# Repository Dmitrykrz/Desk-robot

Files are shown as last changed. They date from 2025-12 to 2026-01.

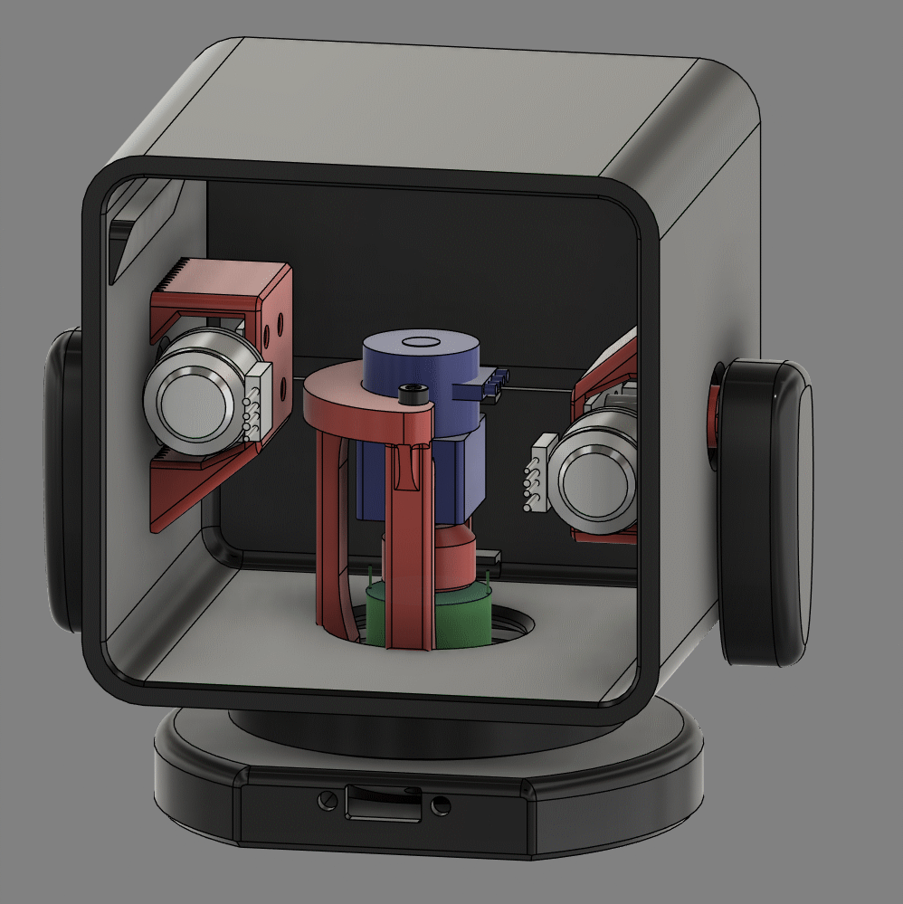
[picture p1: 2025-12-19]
Hardware/internal.png

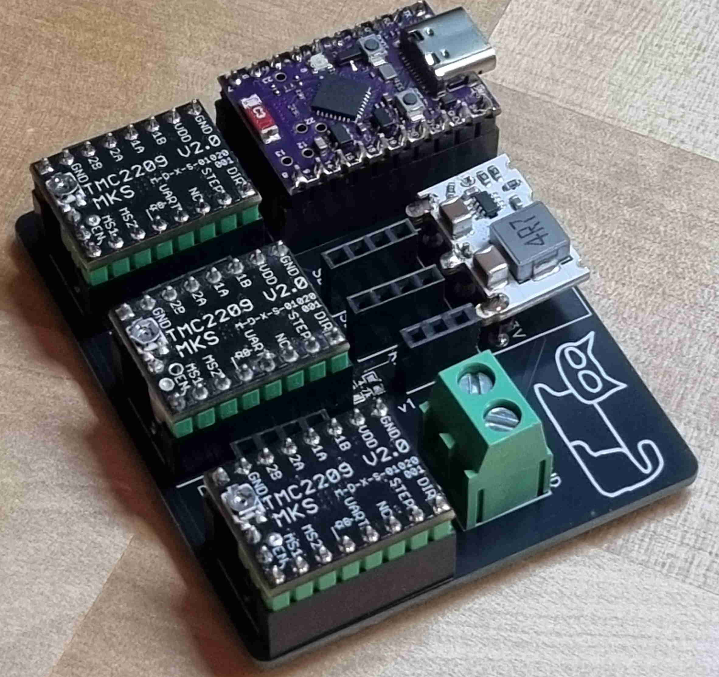
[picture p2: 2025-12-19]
Photos/Desk robot (2).jpg

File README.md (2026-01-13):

# Desk Robot Companion

https://github.com/user-attachments/assets/8fcd8911-27cb-44df-8bd5-095555234ec2

## What is it for?

As with all my projects, I build first and ask questions later. Now that it exists, the answer is clear: this little companion sits on my desk, waves at me when I return from coffee breaks, performs choreographed dances when bored, and generally serves as the world's most overengineered desk buddy.

It detects when I'm present, judges me silently with its LED face, and occasionally spins around dramatically for no reason.

Productivity tool? Emotional support robot? Procrastination enabler? Yes.

Due to the polarizing film with diffuser, the screen is notoriously difficult to capture on camera. It looks far better in person than in any photo here.
The low-ISO image below better represents the real appearance. I love this retro yellow vibe. Each pixel transforms from a point into a vertical rectangle, an artifact of two polarizing films cut at an angle. It gives the face a warmth and texture that photos simply cannot convey.



## Project Structure

- **PCB** — Files and photos for the custom circuit board
- **Hardware** — Fusion 360 design files for the robot body
- **Software** — Arduino code for ESP32-C6

## How It Works

### The Spin

The robot rotates on a large bearing with a 3mm steel shaft running through its center, connecting base to body. A hollow slip ring wraps around this shaft, passing USB power from the stationary base to the spinning upper body—unlimited rotation, no tangled wires, maximum drama.

The base motor drives through a 1:34 gearbox for smooth, theatrical rotations.
internal cut

### The Wave

Both arms use tiny stepper motors with integrated worm gears, giving them that slow, deliberate wave that says *"I acknowledge your existence, human."*

### The Brain

Three TMC2209 stepper drivers live on a custom PCB, commanded by an ESP32-C6. The firmware runs a timeline-based animation system—choreographed sequences of motor movements and facial expressions, all scheduled down to the millisecond.

Desk robot (2)

Desk robot (7)

### The Awareness

A radar module hides behind the face, detecting humans up to 8 meters away. When you approach, it wakes. When you leave, it sulks. The radar's wide spread means no sneaking past unnoticed.

### The Face

An Adafruit Charlieplexed LED matrix—warm yellow, delightfully retro. This display started everything. I saw its glow, imagined a tiny robot companion with emotions rendered in chunky pixels, and the rest became inevitable.

### The Dashboard
The robot is controlled via dashboard built on Node-red. It can be used for manual motor control and for creating face animations



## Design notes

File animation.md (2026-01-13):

# Desk Robot Animation System

## Overview

Timeline-based animation system for ESP32 desk robot with 3 stepper motors and LED matrix face. Commands are scheduled by millisecond timestamps and execute non-blocking in the main loop.

## Hardware

- **base**: Rotating body (stepper motor)
- **left**: Left arm (stepper motor)
- **right**: Right arm (stepper motor)
- **screen**: 8x16 LED matrix displaying emotions (images loaded from Preferences storage)

## Animation JSON Format

Send via MQTT to topic `desk_robot`:
```json
{
  "animation": [
    {"ms": 0, "motor": "base", "pos": 200, "spd": 400, "acc": 800},
    {"ms": 0, "motor": "left", "pos": 100, "spd": 600, "acc": 1200},
    {"ms": 500, "motor": "left", "pos": -100},
    {"ms": 1000, "screen_name": "happy"}    
  ]
}
```

## Command Fields

### Motor commands (base, left, right)

| Field | Required | Description |
|---|---|---|
| `ms` | Yes | Time in milliseconds from animation start |
| `motor` | Yes | Motor: `"base"`, `"left"`, or `"right"` |
| `pos` | Yes | Target position in steps |
| `spd` | No | Speed (steps/sec). If omitted, retains previous value |
| `acc` | No | Acceleration (steps/sec²). If omitted, retains previous value |

### Screen commands

| Field | Required | Description |
|---|---|---|
| `ms` | Yes | Time in milliseconds from animation start |
| `screen` | Yes (or use `screen_name` or `screen_data`) | Image name saved in Preferences (legacy) |
| `screen_name` | Yes (or use `screen` or `screen_data`) | Image name saved in Preferences |
| `screen_data` | Yes (or use `screen` or `screen_name`) | Raw 128-character image data string (8×16, `0` or `1`) |

**Note**: Use either `screen`/`screen_name` (to load saved image) OR `screen_data` (to display raw data without saving).

## Behavior

- Commands must be sorted by `ms` value (ascending)
- Commands with same `ms` value execute together
- Motors operate independently and simultaneously
- Speed/acceleration persist per motor until explicitly changed
- Animation completes when all commands dispatched and all motors stopped
- Maximum 50 commands per animation

## MQTT Responses

Published to `desk_robot_send`:

- `{"animation_started": true, "commands": N}` — animation begun
- `{"animation_complete": true}` — animation finished
- `{"animation_stopped": true}` — animation halted by command

## Animation Control
```json
{"animation_stop": 1}
```
Immediately halts animation and all motors.

## Direct Motor Control

### Base motor

| Command | Description |
|---|---|
| `{"base_move": 200}` | Move base to position 200 |
| `{"base_speed": 400}` | Set speed (also sets acceleration to speed × 2) |
| `{"base_acc": 800}` | Set acceleration independently |
| `{"base_zero": 1}` | Set current position as zero (no movement) |

### Left arm motor

| Command | Description |
|---|---|
| `{"left_move": 200}` | Move left arm to position (-1000 to 1000) |
| `{"left_speed": 400}` | Set speed (also sets acceleration to speed × 2) |
| `{"left_acc": 800}` | Set acceleration independently |
| `{"left_zero": 1}` | Set current position as zero (no movement) |

### Right arm motor

| Command | Description |
|---|---|
| `{"right_move": 200}` | Move right arm to position (-1000 to 1000) |
| `{"right_speed": 400}` | Set speed (also sets acceleration to speed × 2) |
| `{"right_acc": 800}` | Set acceleration independently |
| `{"right_zero": 1}` | Set current position as zero (no movement) |

### All motors

| Command | Description |
|---|---|
| `{"all_zero": 1}` | Set all motors' current position as zero |
| `{"all_home": 1}` | Move all motors to position 0 |

## Screen/Image Commands

### Display image directly

Send 128-character string (8 rows × 16 columns, `0` or `1`): must be 128 long

example of smile face:
{"image":"00100000000001000101000000001010010100000000101001010000000010100010000000000100000000000000000000001000000100000000011111100000"}
example sad face:
{"image":"00100000000001000101000000001010010100000000101000100000000001000000000000000000000001111110000000001100001100000001000000001000"}

### Save current image to storage
```json
{"image_save": "myimage"}
```
Image name must be 1-15 characters. Maximum 10 saved images.

### Load and display saved image
```json
{"image_show": "myimage"}
```

### List all saved images
```json
{"image_show_all": true}
```
Returns: `{"saved_images": ["image1", "image2", ...]}`

### Delete saved image
```json
{"image_delete": "myimage"}
```

## Radar Control

| Command | Description |
|---|---|
| `{"radarenable": 1}` | Enable radar human detection |
| `{"radarenable": 0}` | Disable radar human detection |

When enabled, publishes `{"human": 1}` or `{"human": 0}` on detection changes.

## System Commands

| Command | Description |
|---|---|
| `{"command": "reset"}` | Restart the ESP32 |

## Example Animations

### Animation with raw image data (no saving required)
```json
{
  "animation": [
    {"ms": 0, "screen_data": "00100000000001000101000000001010010100000000101001010000000010100010000000000100000000000000000000001000000100000000011111100000"},
    {"ms": 500, "screen_data": "00100000000001000101000000001010010100000000101000100000000001000000000000000000000001111110000000001100001100000001000000001000"},
    {"ms": 1000, "screen_name": "smile1"}
  ]
}
```

### Simple wave
```json
{
  "animation": [
    {"ms": 0, "motor": "left", "pos": 200, "spd": 800, "acc": 1600},
    {"ms": 300, "motor": "left", "pos": -200},
    {"ms": 600, "motor": "left", "pos": 200},
    {"ms": 900, "motor": "left", "pos": -200},
    {"ms": 1200, "motor": "left", "pos": 0}
  ]
}
```

### Dance (base rotation with arm waves)
```json
{
  "animation": [
    {"ms": 0, "screen": "happy"},
    {"ms": 0, "motor": "base", "pos": 300, "spd": 100, "acc": 200},
    {"ms": 0, "motor": "left", "pos": 200, "spd": 800, "acc": 1600},
    {"ms": 0, "motor": "right", "pos": -200, "spd": 800, "acc": 1600},
    {"ms": 400, "motor": "left", "pos": -200},
    {"ms": 400, "motor": "right", "pos": 200},
    {"ms": 800, "motor": "left", "pos": 200},
    {"ms": 800, "motor": "right", "pos": -200},
    {"ms": 1200, "motor": "left", "pos": -200},
    {"ms": 1200, "motor": "right", "pos": 200},
    {"ms": 1600, "motor": "left", "pos": 0},
    {"ms": 1600, "motor": "right", "pos": 0},
    {"ms": 2000, "motor": "base", "pos": 0},
    {"ms": 2500, "screen": "smile"}
  ]
}
```

### Excited greeting (fast arm movement while nodding)
```json
{
  "animation": [
    {"ms": 0, "screen": "excited"},
    {"ms": 0, "motor": "left", "pos": 300, "spd": 1000, "acc": 2000},
    {"ms": 0, "motor": "right", "pos": 300, "spd": 1000, "acc": 2000},
    {"ms": 0, "motor": "base", "pos": 50, "spd": 200, "acc": 800},
    {"ms": 200, "motor": "left", "pos": 100},
    {"ms": 200, "motor": "right", "pos": 100},
    {"ms": 200, "motor": "base", "pos": -50},
    {"ms": 400, "motor": "left", "pos": 300},
    {"ms": 400, "motor": "right", "pos": 300},
    {"ms": 400, "motor": "base", "pos": 50},
    {"ms": 600, "motor": "left", "pos": 100},
    {"ms": 600, "motor": "right", "pos": 100},
    {"ms": 600, "motor": "base", "pos": -50},
    {"ms": 800, "motor": "left", "pos": 0},
    {"ms": 800, "motor": "right", "pos": 0},
    {"ms": 800, "motor": "base", "pos": 0},
    {"ms": 1000, "screen": "smile"}
  ]
}
```

## Jog Commands (Relative Movement)

Jog commands move motors relative to their current position, unlike `*_move` commands which use absolute positioning.

| Command | Description |
|---|---|
| `{"base_jog": 100}` | Move base 100 steps from current position |
| `{"base_jog": -100}` | Move base -100 steps from current position |
| `{"left_jog": 50}` | Move left arm 50 steps from current position |
| `{"left_jog": -50}` | Move left arm -50 steps from current position |
| `{"right_jog": 50}` | Move right arm 50 steps from current position |
| `{"right_jog": -50}` | Move right arm -50 steps from current position |

Jog commands are useful for manual positioning and fine-tuning without tracking absolute positions.

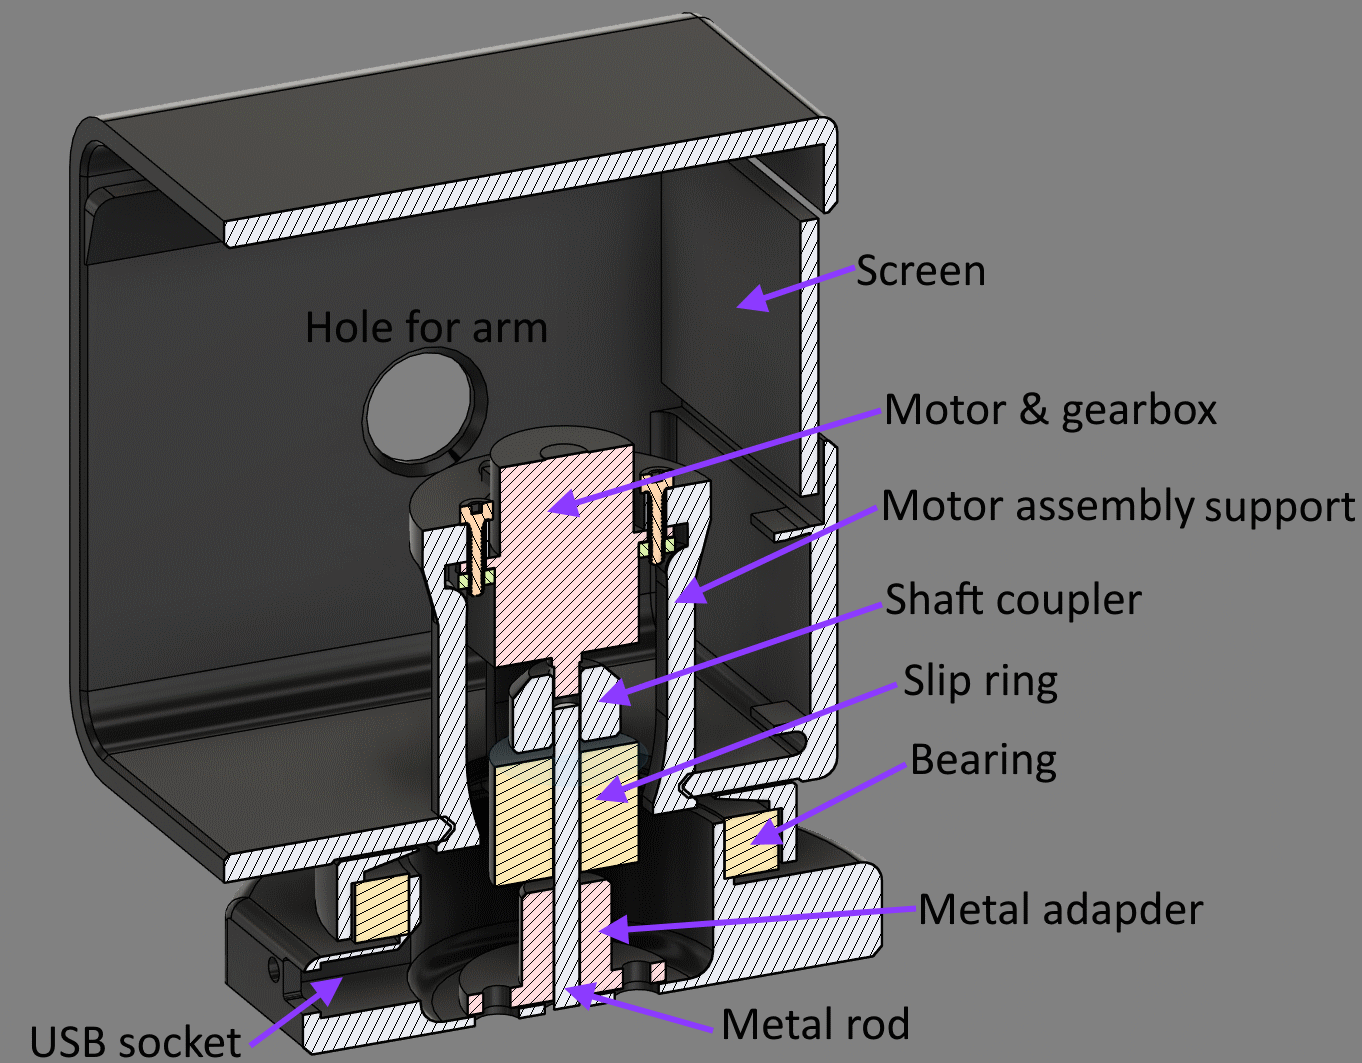
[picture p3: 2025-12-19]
Hardware/internal cut.png

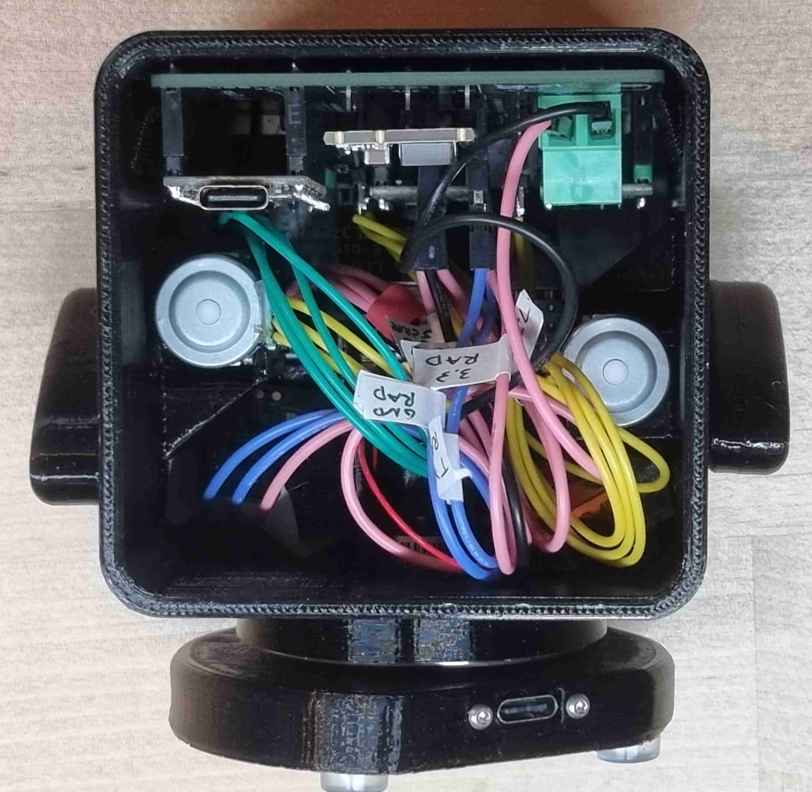
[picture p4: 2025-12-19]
Photos/Desk robot (7).jpg

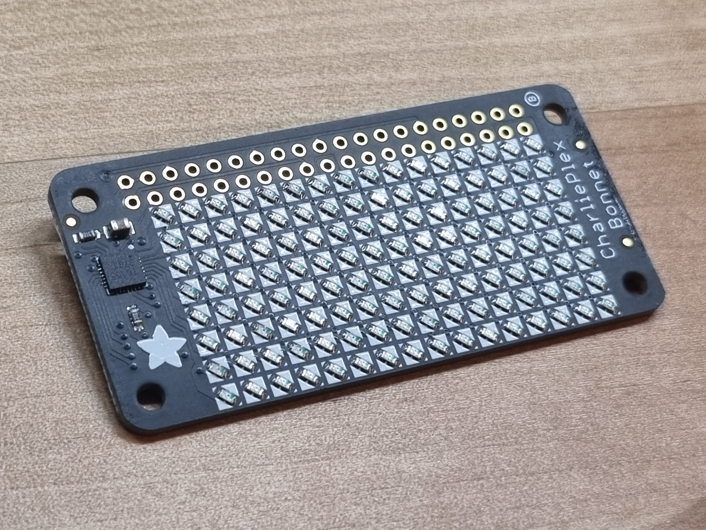
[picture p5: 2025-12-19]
Photos/Desk robot (5).jpg

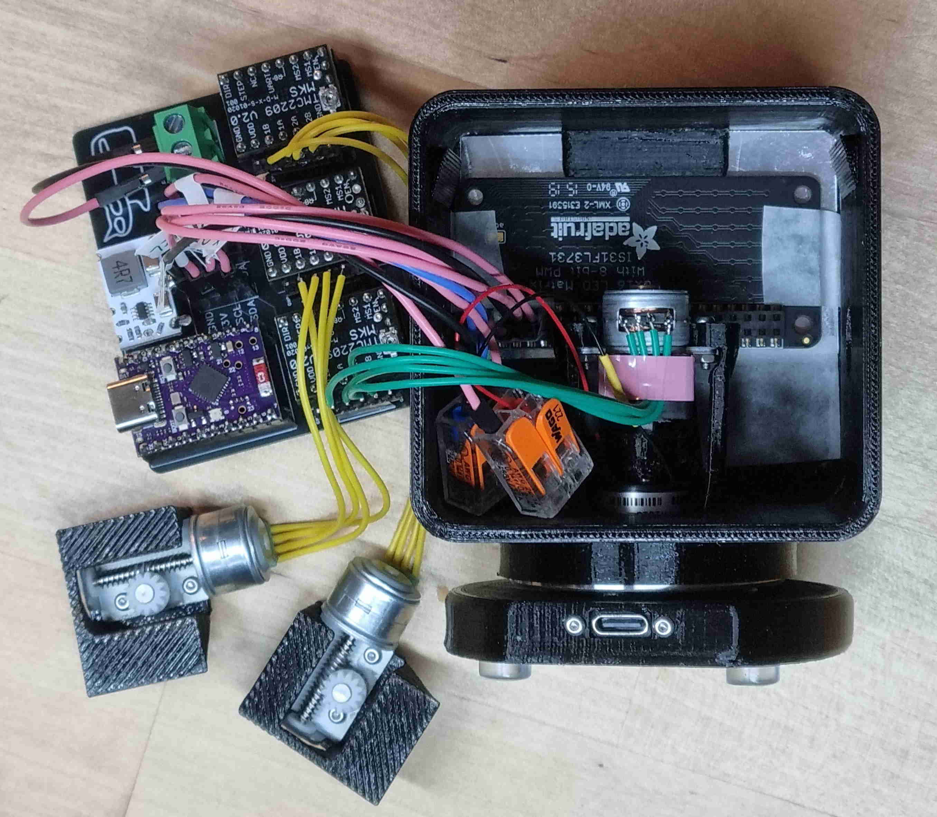
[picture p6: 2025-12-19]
Photos/Desk robot (4).jpg

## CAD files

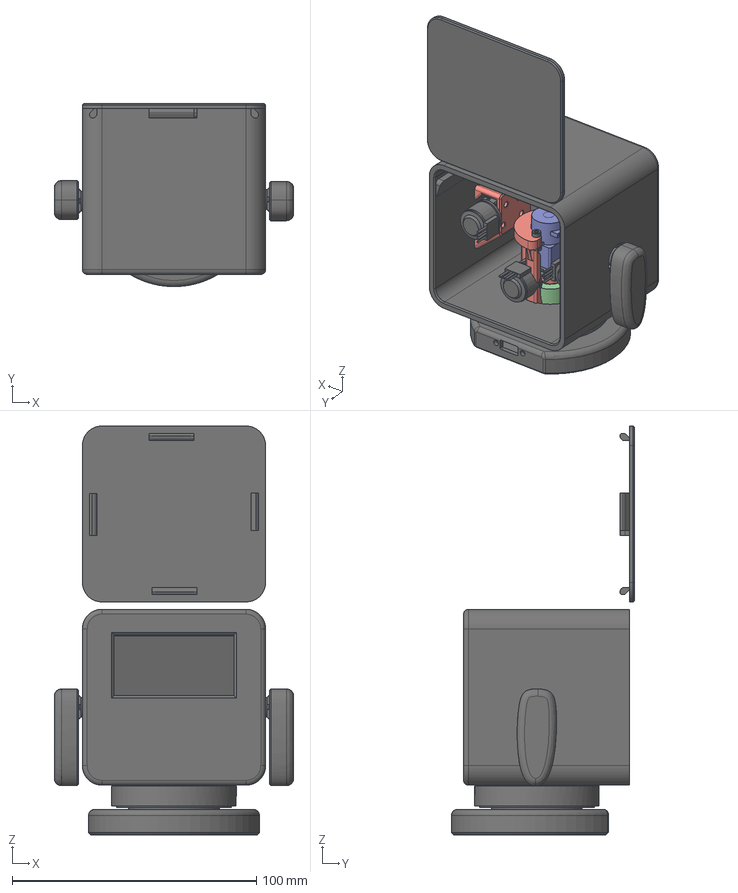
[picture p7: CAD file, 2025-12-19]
Hardware/Desk-robot.step
98.0 x 75.0 x 167.4 mm
90591A265_Zinc-Plated Steel Hex Nut x 2
91292A832_18-8 Stainless Steel Socket Head Screw x 2

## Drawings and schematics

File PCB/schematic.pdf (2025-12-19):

# TMC2209 Stepper motor drivers

11 11 12 12 13 13 14 14 15 15 16 16 17 17 18 18 19 19 20 20

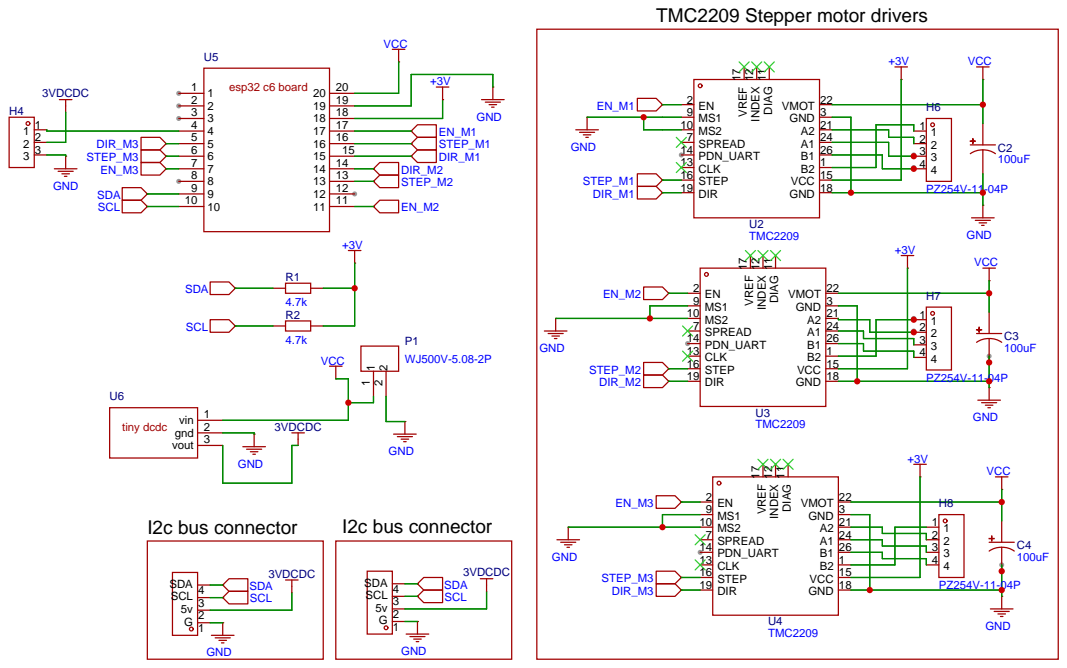
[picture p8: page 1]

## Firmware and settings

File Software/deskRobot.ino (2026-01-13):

#include <Arduino.h>

#include <Korzhenevskiy_tick_tack_2.h>
#include <Korzhenevskiy_utils.h>
#include "secrets.h"
#include "Radar.h"
#include <math.h>
#include "WiFi.h"
#include <WiFiClient.h>
#include <PubSubClient.h>
#include <ArduinoJson.h>
#include <AccelStepper.h>
#include <Wire.h>
#include <Adafruit_GFX.h>
#include <Adafruit_IS31FL3731.h>
#include <Preferences.h>

// ===================================================================================
// PIN DEFINITIONS
// ===================================================================================

#define motor_base_dir 18 // correct
#define motor_base_step 19 // correct
#define motor_base_enable 20 // correct

#define motor_arm_left_dir 15 // correct but not tested
#define motor_arm_left_step 14 // correct but not tested
#define motor_arm_left_enable 8// correct but not tested

#define motor_arm_right_dir 2 // correct but not tested
#define motor_arm_right_step 3 // correct but not tested
#define motor_arm_right_enable 4 // correct but not tested

// ===================================================================================
// MOTOR CONFIGURATION
// ===================================================================================

int motor_base_speed = 400;
int motor_base_accel = motor_base_speed * 2;

int motor_left_speed = 400;
int motor_left_accel = motor_left_speed * 2;

int motor_right_speed = 400;
int motor_right_accel = motor_right_speed * 2;

AccelStepper stepper_base(1, motor_base_step, motor_base_dir);
AccelStepper stepper_left(1, motor_arm_left_step, motor_arm_left_dir);
AccelStepper stepper_right(1, motor_arm_right_step, motor_arm_right_dir);

// ===================================================================================
// DISPLAY AND STORAGE
// ===================================================================================

Adafruit_IS31FL3731 ledmatrix = Adafruit_IS31FL3731();
Preferences preferences;

int currentImage[8][16];
String globalConfigStatus = "";

#define MAX_SAVED_IMAGES 10

// ===================================================================================
// RADAR SENSOR
// ===================================================================================

Radar radar(1, Serial1);
bool radar_debounced_old = false;

// ===================================================================================
// NETWORK
// ===================================================================================

WiFiClient espClient;
byte mac[6];
IPAddress ip;
PubSubClient client(espClient);

// ===================================================================================
// ANIMATION SYSTEM
// ===================================================================================

#define MAX_ANIMATION_COMMANDS 90

struct AnimationCommand {
  unsigned long t;      // time in ms from animation start
  char motor;           // 'B' = base, 'L' = left, 'R' = right, 'F' = face, 'D' = face raw data
  int pos;              // target position (for motors)
  int spd;              // speed (-1 = keep previous)
  int acc;              // acceleration (-1 = keep previous)
  String img;           // image name or raw data string (for face commands)
};

AnimationCommand animationCommands[MAX_ANIMATION_COMMANDS];
int animationCommandCount = 0;
int animationCurrentIndex = 0;
unsigned long animationStartTime = 0;
bool animationRunning = false;

// ===================================================================================
// RADAR TIMERS
// ===================================================================================
void publish_radar_status();
void publish_radar_range();
Korzhenevskiy_tick_tack_2 timer_radar(publish_radar_status, 10000);
Korzhenevskiy_tick_tack_2 timer_radar_range(publish_radar_range, 1000);

// ===================================================================================
// FUNCTION DECLARATIONS
// ===================================================================================

void callback(char* topic, byte* payload, unsigned int length);
void draw_image(const int image[8][16]);


void read_storage_for_config();
void publish_config_status();
void save_config_to_preferences(String key, int value);
void save_config_to_preferences(String key, bool value);
void saveImageToPreferences(String name);
void loadImageFromPreferences(String name);
void listSavedImages();
void deleteImageFromPreferences(String name);
void parseAnimation(JsonArray arr);
void tickAnimation();
void stopAnimation();



// ===================================================================================
// CONFIG STORAGE FUNCTIONS
// ===================================================================================

void read_storage_for_config() {
  preferences.begin("config", true);
  
  globalConfigStatus = "";
  
  if (preferences.isKey("base_speed")) {
    motor_base_speed = preferences.getInt("base_speed", 400);
    String msg = "base_speed loaded from storage: " + String(motor_base_speed);
    Serial.println(msg);
    globalConfigStatus += msg + "; ";
  } else {
    motor_base_speed = 400;
    String msg = "base_speed not in storage, loaded default value: 400";
    Serial.println(msg);
    globalConfigStatus += msg + "; ";
  }
  motor_base_accel = motor_base_speed * 2;
  stepper_base.setMaxSpeed(motor_base_speed);
  stepper_base.setAcceleration(motor_base_accel);
  
  if (preferences.isKey("left_speed")) {
    motor_left_speed = preferences.getInt("left_speed", 400);
  } else {
    motor_left_speed = 400;
  }
  motor_left_accel = motor_left_speed * 2;
  stepper_left.setMaxSpeed(motor_left_speed);
  stepper_left.setAcceleration(motor_left_accel);
  
  if (preferences.isKey("right_speed")) {
    motor_right_speed = preferences.getInt("right_speed", 400);
  } else {
    motor_right_speed = 400;
  }
  motor_right_accel = motor_right_speed * 2;
  stepper_right.setMaxSpeed(motor_right_speed);
  stepper_right.setAcceleration(motor_right_accel);
  
  
  
  
  
  
  preferences.end();
  
  Serial.println("Configuration loading complete");
}

void publish_config_status() {
  Serial.println("publish_config_status");
  String mqttMessage = "{\"config_status\": \"" + globalConfigStatus + "\"}";
  client.publish(MQTTChannelToPublish, mqttMessage.c_str());
  Serial.println("Config status published to MQTT");
}

void save_config_to_preferences(String key, int value) {
  preferences.begin("config", false);
  preferences.putInt(key.c_str(), value);
  preferences.end();
  Serial.print("Saved config: ");
  Serial.print(key);
  Serial.print(" = ");
  Serial.println(value);
}

void save_config_to_preferences(String key, bool value) {
  preferences.begin("config", false);
  preferences.putBool(key.c_str(), value);
  preferences.end();
  Serial.print("Saved config: ");
  Serial.print(key);
  Serial.print(" = ");
  Serial.println(value ? "true" : "false");
}

// ===================================================================================
// IMAGE STORAGE FUNCTIONS
// ===================================================================================

void saveImageToPreferences(String name) {
  if (name.length() == 0 || name.length() > 15) {
    Serial.println("Error: Image name must be 1-15 characters");
    client.publish(MQTTChannelToPublish, "{\"error\": \"Image name must be 1-15 characters\"}");
    return;
  }

  preferences.begin("images", false);
  
  String imageList = preferences.getString("image_list", "");
  
  int nameCount = 0;
  if (imageList.length() > 0) {
    int startPos = 0;
    while (startPos < (int)imageList.length()) {
      int endPos = imageList.indexOf(',', startPos);
      if (endPos == -1) endPos = imageList.length();
      nameCount++;
      startPos = endPos + 1;
    }
  }
  
  bool nameExists = false;
  if (imageList.indexOf(name) != -1) {
    int startPos = 0;
    while (startPos < (int)imageList.length()) {
      int endPos = imageList.indexOf(',', startPos);
      if (endPos == -1) endPos = imageList.length();
      String existingName = imageList.substring(startPos, endPos);
      if (existingName.equals(name)) {
        nameExists = true;
        break;
      }
      startPos = endPos + 1;
    }
  }
  
  if (!nameExists && nameCount >= MAX_SAVED_IMAGES) {
    Serial.println("Error: Maximum number of saved images reached");
    client.publish(MQTTChannelToPublish, "{\"error\": \"Maximum number of saved images reached\"}");
    preferences.end();
    return;
  }
  
  uint8_t imageData[16];
  for (int byteIdx = 0; byteIdx < 16; byteIdx++) {
    imageData[byteIdx] = 0;
    for (int bitIdx = 0; bitIdx < 8; bitIdx++) {
      int row = byteIdx / 2;
      int col = (byteIdx % 2) * 8 + bitIdx;
      if (currentImage[row][col] == 1) {
        imageData[byteIdx] |= (1 << bitIdx);
      }
    }
  }
  
  preferences.putBytes(name.c_str(), imageData, 16);
  
  if (!nameExists) {
    if (imageList.length() > 0) {
      imageList += ",";
    }
    imageList += name;
    preferences.putString("image_list", imageList);
  }
  
  preferences.end();
  
  Serial.print("Image saved: ");
  Serial.println(name);
  
  String response = "{\"image_saved\": \"" + name + "\"}";
  client.publish(MQTTChannelToPublish, response.c_str());
}

void loadImageFromPreferences(String name) {
  preferences.begin("images", true);
  
  if (!preferences.isKey(name.c_str())) {
    Serial.print("Error: Image not found: ");
    Serial.println(name);
    String response = "{\"error\": \"Image not found: " + name + "\"}";
    client.publish(MQTTChannelToPublish, response.c_str());
    preferences.end();
    return;
  }
  
  uint8_t imageData[16];
  size_t len = preferences.getBytes(name.c_str(), imageData, 16);
  
  if (len != 16) {
    Serial.println("Error: Corrupted image data");
    client.publish(MQTTChannelToPublish, "{\"error\": \"Corrupted image data\"}");
    preferences.end();
    return;
  }
  
  preferences.end();
  
  int loadedImage[8][16];
  for (int byteIdx = 0; byteIdx < 16; byteIdx++) {
    for (int bitIdx = 0; bitIdx < 8; bitIdx++) {
      int row = byteIdx / 2;
      int col = (byteIdx % 2) * 8 + bitIdx;
      loadedImage[row][col] = (imageData[byteIdx] & (1 << bitIdx)) ? 1 : 0;
    }
  }
  
  draw_image(loadedImage);
  
  Serial.print("Image loaded and displayed: ");
  Serial.println(name);
  
  String response = "{\"image_loaded\": \"" + name + "\"}";
  client.publish(MQTTChannelToPublish, response.c_str());
}

void listSavedImages() {
  preferences.begin("images", true);
  
  String imageList = preferences.getString("image_list", "");
  preferences.end();
  
  if (imageList.length() == 0) {
    client.publish(MQTTChannelToPublish, "{\"saved_images\": []}");
    Serial.println("No saved images");
    return;
  }
  
  String jsonResponse = "{\"saved_images\": [";
  int startPos = 0;
  bool first = true;
  
  while (startPos < (int)imageList.length()) {
    int endPos = imageList.indexOf(',', startPos);
    if (endPos == -1) endPos = imageList.length();
    
    String imageName = imageList.substring(startPos, endPos);
    
    if (!first) {
      jsonResponse += ", ";
    }
    jsonResponse += "\"" + imageName + "\"";
    first = false;
    
    startPos = endPos + 1;
  }
  
  jsonResponse += "]}";
  
  Serial.print("Saved images: ");
  Serial.println(jsonResponse);
  
  client.publish(MQTTChannelToPublish, jsonResponse.c_str());
}

void deleteImageFromPreferences(String name) {
  preferences.begin("images", false);
  
  if (!preferences.isKey(name.c_str())) {
    Serial.print("Error: Image not found: ");
    Serial.println(name);
    preferences.end();
    return;
  }
  
  preferences.remove(name.c_str());
  
  String imageList = preferences.getString("image_list", "");
  String newList = "";
  int startPos = 0;
  bool first = true;
  
  while (startPos < (int)imageList.length()) {
    int endPos = imageList.indexOf(',', startPos);
    if (endPos == -1) endPos = imageList.length();
    
    String imageName = imageList.substring(startPos, endPos);
    
    if (!imageName.equals(name)) {
      if (!first) {
        newList += ",";
      }
      newList += imageName;
      first = false;
    }
    
    startPos = endPos + 1;
  }
  
  preferences.putString("image_list", newList);
  preferences.end();
  
  Serial.print("Image deleted: ");
  Serial.println(name);
  
  String response = "{\"image_deleted\": \"" + name + "\"}";
  client.publish(MQTTChannelToPublish, response.c_str());
}

// ===================================================================================
// ANIMATION SYSTEM FUNCTIONS
// ===================================================================================
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
void loop() {
  // Motor enable control - enable only when running
  if (stepper_base.isRunning()) digitalWrite(motor_base_enable, LOW);
  else digitalWrite(motor_base_enable, HIGH);
  
  if (stepper_left.isRunning()) digitalWrite(motor_arm_left_enable, LOW);
  else digitalWrite(motor_arm_left_enable, HIGH);
  
  if (stepper_right.isRunning()) digitalWrite(motor_arm_right_enable, LOW);
  else digitalWrite(motor_arm_right_enable, HIGH);
  
  // Run all steppers
  stepper_base.run();
  stepper_left.run();
  stepper_right.run();
  
  // Tick animation system
  tickAnimation();
  
  // Tick timers
  Korzhenevskiy_tick_tack_2::mass_tick();

  // Update radar continuously
  radar.update();

  // Immediate publish when radar detects presence (asymmetric behavior)
  bool radar_debounced_current = radar.check_debounced();
  if (radar_debounced_current && !radar_debounced_old) {
    client.publish(MQTTChannelToPublish, "{\"radar\": true}");
    Serial.println("Radar: Human detected (immediate)");
  }
  radar_debounced_old = radar_debounced_current;
  
  // MQTT reconnection
  if (!client.connected()) {
    connecttoMQTT();
  }
  client.loop();
}

// ===================================================================================
// MQTT CALLBACK
// ===================================================================================

void callback(char* topic, byte* payload, unsigned int length) {
  String message;
  
  for (unsigned int i = 0; i < length; i++) {
    message = message + (char)payload[i];
  }
  Serial.print("New message from MQTT: ");
  Serial.println(message);
  
  DynamicJsonDocument doc(4096);  // Increased size for animations
  
  DeserializationError error = deserializeJson(doc, message);
  if (error) {
    Serial.print(F("deserializeJson() failed with code "));
    Serial.println(error.c_str());
    return;
  }
  
  Serial.println("JSON parse success");
  
  // ---------------------------------------------------------------------------------
  // ANIMATION COMMAND
  // ---------------------------------------------------------------------------------
  if (doc.containsKey("animation")) {
    JsonArray arr = doc["animation"].as<JsonArray>();
    parseAnimation(arr);
    return;  // Animation takes priority, ignore other commands in same message
  }
  
  // ---------------------------------------------------------------------------------
  // ANIMATION STOP
  // ---------------------------------------------------------------------------------
  if (doc.containsKey("animation_stop")) {
    stopAnimation();
  }
  
  // ---------------------------------------------------------------------------------
  // SYSTEM COMMANDS
  // ---------------------------------------------------------------------------------
  if (doc.containsKey("command")) {
    String command = doc["command"];
    if (command == "reset") ESP.restart();
  }
  
  // ---------------------------------------------------------------------------------
  // IMAGE COMMANDS
  // ---------------------------------------------------------------------------------
  if (doc.containsKey("image")) {
    String imageString = doc["image"];
    Serial.println("Image received:");
    Serial.println(imageString);
    int Image[8][16];
    if (imageString.length() == 128) {
      int index = 0;
      for (int row = 0; row < 8; row++) {
        for (int col = 0; col < 16; col++) {
          Image[row][col] = imageString.charAt(index) - '0';
          index++;
        }
      }
      Serial.println("Image array populated successfully");
      draw_image(Image);
    } else {
      Serial.println("Error: Image string length is not 128");
    }
  }
  
  if (doc.containsKey("image_save")) {
    String imageName = doc["image_save"].as<String>();
    saveImageToPreferences(imageName);
  }
  
  if (doc.containsKey("image_show")) {
    String imageName = doc["image_show"].as<String>();
    loadImageFromPreferences(imageName);
  }
  
  if (doc.containsKey("image_show_all")) {
    listSavedImages();
  }
  
  if (doc.containsKey("image_delete")) {
    String imageName = doc["image_delete"].as<String>();
    deleteImageFromPreferences(imageName);
  }
  
  // ---------------------------------------------------------------------------------
  // BASE MOTOR DIRECT CONTROL
  // ---------------------------------------------------------------------------------
  if (doc.containsKey("base_move")) {
    int Value = doc["base_move"];
   
      stepper_base.moveTo(Value);
    
  }
  
  if (doc.containsKey("base_zero")) {
    stepper_base.setCurrentPosition(0);
    Serial.println("base set to home");
  }
  
  if (doc.containsKey("base_speed")) {
    int Value = doc["base_speed"];
    motor_base_speed = Value;
    motor_base_accel = Value * 2;
    stepper_base.setMaxSpeed(Value);
    stepper_base.setAcceleration(motor_base_accel);
    save_config_to_preferences("base_speed", Value);
    Serial.print("base speed/accel changed: ");
    Serial.println(Value);
  }
  
  if (doc.containsKey("base_acc")) {
    int Value = doc["base_acc"];
    motor_base_accel = Value;
    stepper_base.setAcceleration(Value);
    Serial.print("base acceleration changed to ");
    Serial.println(Value);
  }
  
  // ---------------------------------------------------------------------------------
  // LEFT ARM MOTOR DIRECT CONTROL
  // ---------------------------------------------------------------------------------
  if (doc.containsKey("left_move")) {
    int Value = doc["left_move"];
    if (Value >= -1000 && Value <= 1000) {
      stepper_left.moveTo(Value);
    }
  }
  
  if (doc.containsKey("left_zero")) {
    stepper_left.setCurrentPosition(0);
    Serial.println("left arm set to home");
  }
  
  if (doc.containsKey("left_speed")) {
    int Value = doc["left_speed"];
    motor_left_speed = Value;
    motor_left_accel = Value * 2;
    stepper_left.setMaxSpeed(Value);
    stepper_left.setAcceleration(motor_left_accel);
    save_config_to_preferences("left_speed", Value);
    Serial.print("left speed/accel changed: ");
    Serial.println(Value);
  }
  
  if (doc.containsKey("left_acc")) {
    int Value = doc["left_acc"];
    motor_left_accel = Value;
    stepper_left.setAcceleration(Value);
    Serial.print("left acceleration changed to ");
    Serial.println(Value);
  }
  
  // ---------------------------------------------------------------------------------
  // RIGHT ARM MOTOR DIRECT CONTROL
  // ---------------------------------------------------------------------------------
  if (doc.containsKey("right_move")) {
    int Value = doc["right_move"];
    if (Value >= -1000 && Value <= 1000) {
      stepper_right.moveTo(Value);
    }
  }
  
  if (doc.containsKey("right_zero")) {
    stepper_right.setCurrentPosition(0);
    Serial.println("right arm set to home");
  }
  
  if (doc.containsKey("right_speed")) {
    int Value = doc["right_speed"];
    motor_right_speed = Value;
    motor_right_accel = Value * 2;
    stepper_right.setMaxSpeed(Value);
    stepper_right.setAcceleration(motor_right_accel);
    save_config_to_preferences("right_speed", Value);
    Serial.print("right speed/accel changed: ");
    Serial.println(Value);
  }
  
  if (doc.containsKey("right_acc")) {
    int Value = doc["right_acc"];
    motor_right_accel = Value;
    stepper_right.setAcceleration(Value);
    Serial.print("right acceleration changed to ");
    Serial.println(Value);
  }
  
  // ---------------------------------------------------------------------------------
  // ALL MOTORS ZERO
  // ---------------------------------------------------------------------------------
  if (doc.containsKey("all_zero")) {
    stepper_base.setCurrentPosition(0);
    stepper_left.setCurrentPosition(0);
    stepper_right.setCurrentPosition(0);
    Serial.println("all motors set to home");
    client.publish(MQTTChannelToPublish, "{\"all_zero\": true}");
  }
  
  // ---------------------------------------------------------------------------------
  // ALL MOTORS HOME (move to 0)
  // ---------------------------------------------------------------------------------
  if (doc.containsKey("all_home")) {
    stepper_base.moveTo(0);
    stepper_left.moveTo(0);
    stepper_right.moveTo(0);
    Serial.println("all motors moving to home");
    client.publish(MQTTChannelToPublish, "{\"all_home\": true}");
  }
// ---------------------------------------------------------------------------------
// JOG COMMANDS (relative movement)
// ---------------------------------------------------------------------------------
if (doc.containsKey("base_jog")) {
  int Value = doc["base_jog"];
  long current = stepper_base.currentPosition();
  stepper_base.moveTo(current + Value);
  Serial.print("base jog: ");
  Serial.println(current + Value);
}
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

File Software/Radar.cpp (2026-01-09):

#include "Radar.h"

Radar::Radar(int rx_pin, HardwareSerial& serialPort)
  : rxPin(rx_pin), serial(&serialPort), historyIndex(0), debounced(false), historySize(100),
    rangeSum(0), rangeCount(0), rangeAverageSize(10), rangeAverage(0) {
  // Initialize history to all false
  for (int i = 0; i < RADAR_HISTORY_SIZE_MAX; i++) {
    history[i] = false;
  }
}

void Radar::begin(long baudRate) {
  serial->begin(baudRate, SERIAL_8N1, rxPin, -1);
}

void Radar::update() {
  // Note: Radar sends data at approximately 10 Hz (~105ms interval)
  // So historySize of 100 = ~10 seconds of data

  if (serial->available()) {
    String receivedString = serial->readStringUntil('\n');
    receivedString.trim();

    if (receivedString.length() > 0) {
      // Check for presence detection (ON/OFF)
      if (receivedString.equals("ON") || receivedString.equals("OFF")) {
        bool currentReading = receivedString.equals("ON");

        // Add to circular buffer
        history[historyIndex] = currentReading;
        historyIndex = (historyIndex + 1) % historySize;

        // Check if all history is false (up to current historySize)
        bool allFalse = true;
        for (int i = 0; i < historySize; i++) {
          if (history[i]) {
            allFalse = false;
            break;
          }
        }

        // Asymmetric debouncing: fast ON, slow OFF
        if (currentReading) {
          debounced = true;
        } else if (allFalse) {
          debounced = false;
        }
      }
      // Check for range data (e.g., "Range 72")
      else if (receivedString.startsWith("Range ")) {
        int rangeValue = receivedString.substring(6).toInt();

        // Accumulate for averaging
        rangeSum += rangeValue;
        rangeCount++;

        // Calculate average when we have enough samples
        if (rangeCount >= rangeAverageSize) {
          rangeAverage = rangeSum / rangeCount;
          rangeSum = 0;
          rangeCount = 0;
        }
      }
    }
  }
}

bool Radar::check() {
  // Returns most recent reading from history
  int prevIndex = (historyIndex - 1 + historySize) % historySize;
  return history[prevIndex];
}

bool Radar::check_debounced() {
  return debounced;
}

void Radar::set_history_size(int size) {
  // Validate size
  if (size < 1) size = 1;
  if (size > RADAR_HISTORY_SIZE_MAX) size = RADAR_HISTORY_SIZE_MAX;

  historySize = size;

  // Reset history index to avoid issues with wraparound
  historyIndex = 0;

  // Clear history when changing size
  for (int i = 0; i < RADAR_HISTORY_SIZE_MAX; i++) {
    history[i] = false;
  }

  Serial.print("Radar history size set to: ");
  Serial.println(historySize);
}

int Radar::get_history_size() {
  return historySize;
}

int Radar::get_range() {
  return rangeAverage;
}

void Radar::set_range_average_size(int size) {
  if (size < 1) size = 1;
  if (size > 100) size = 100;

  rangeAverageSize = size;

  // Reset averaging counters
  rangeSum = 0;
  rangeCount = 0;

  Serial.print("Radar range average size set to: ");
  Serial.println(rangeAverageSize);
}

int Radar::get_range_average_size() {
  return rangeAverageSize;
}
